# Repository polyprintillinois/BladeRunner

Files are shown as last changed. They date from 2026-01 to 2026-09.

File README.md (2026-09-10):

# BladeRunner - Linear Stage Controller

This repository accompanies **Hwang, Elangovan, Damron, Kwok, Jeon & Diao, "Democratizing Lab Automation through Multi-Agent-Assisted Design and 3D Printing"** (submitted, 2026). Archived release: [Zenodo DOI 10.5281/zenodo.22695750](https://doi.org/10.5281/zenodo.22695750). Code is released under the MIT licence; printed-part designs (STL) and documentation may be reused under the same terms with attribution.

**BladeRunner** is a high-precision linear stage control system powered by Arduino firmware and a Python Tkinter GUI. It provides safe, user-friendly control of a stepper-driven linear actuator with adjustable speed and acceleration.

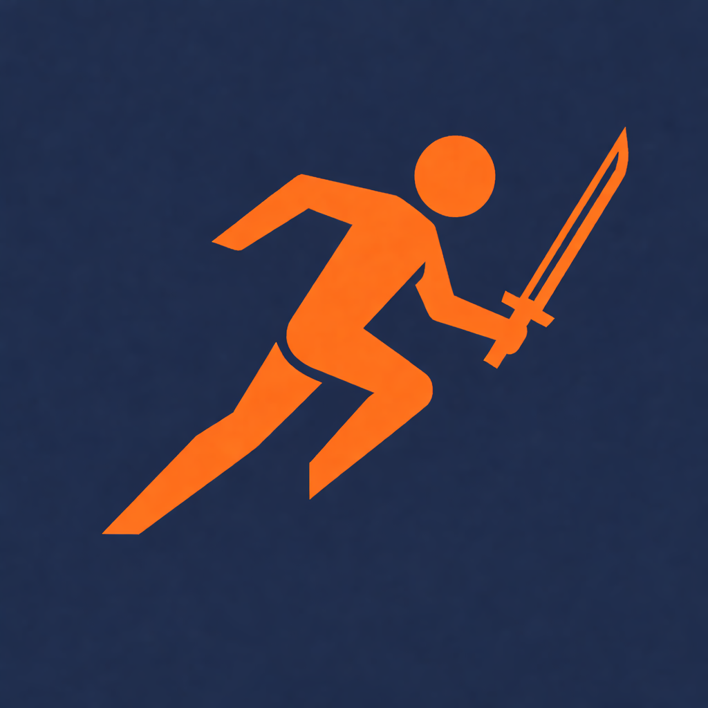
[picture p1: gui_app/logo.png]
BladeRunner Icon


## Documentation

- [Hardware Assembly Guide](docs/hardware-assembly-guide.md)
- [Implementation Guide](docs/implementation-guide.md)

To assemble, wire, and operate the system from scratch, use the Hardware Assembly Guide and Implementation Guide together.

## Features

- **Precise Control**: Move to absolute positions or jog in relative steps.
- **Reliable Operation**: Blocking homing routine, software stop (decelerated via `AccelStepper.stop()`), and software travel limits from 0 to 45 mm.
- **Adjustable Parameters**: Real-time control of speed (mm/s) and acceleration (mm/s^2).
- **Robust Communication**: Custom serial protocol with error handling and status feedback.

## Hardware Requirements

- **Microcontroller**: Arduino Uno R4 Minima
- **Driver**: Adafruit TMC2209 breakout in DIR/STEP mode
- **Motor**: NEMA 17 stepper motor (for example, StepperOnline 17HS08-1004S)
- **Actuator**: Linear rail/stage with 45 mm travel

## Safety

- The stage is driven by a 12 V supply. Disconnect power before wiring or swapping stepper leads.
- The carriage moves at up to 30 mm/s and can pinch fingers against the end stops; keep hands clear during homing and moves. The **EMERGENCY STOP** button performs a decelerated software stop via `AccelStepper.stop()`—it is not a hardware emergency stop.
- The blade is a thin glass or silicon piece with a sharp edge; handle it with tweezers.
- When printing with solvents (for example, chlorobenzene), operate inside a fume hood or with adequate ventilation. The 3D-printed PLA parts are not solvent-resistant and should be kept dry.

## Operating Constraints

- **Travel Limit**: The controller enforces a 45 mm software travel limit. Ensure the physical stage matches this usable range.
- **Homing Requirement**: The system must be homed after connecting before motion commands are enabled.
- **Blocking Homing**: The homing sequence blocks on the Arduino side until the limit switch is hit or the 20-second timeout expires. The software-stop command is still checked during this routine.
- **Speed and Acceleration Limits**: The GUI caps speed at 30 mm/s and acceleration at 1000 mm/s^2 to reduce the chance of stalls or mechanical damage.

## Installation and Usage

### Method 1: Executable

No Python installation is required.

1. Go to the **[Releases](../../releases)** page of this repository.
2. Download the latest `BladeRunner.exe` from the Assets section.
3. Connect the Arduino over USB and run the executable.

### Method 2: Run from Source

1. Install Python 3.x.
2. Install dependencies:

```bash
pip install -r requirements.txt
```

3. Run the application:

```bash
python gui_app/main.py
```

### Firmware Setup

1. Open `firmware/stepper_controller/stepper_controller.ino` in Arduino IDE.
2. Install the `AccelStepper` library.
3. Upload the firmware to the Arduino board.

## First Run (Hello World)

A minimal test that confirms the stage, firmware, and GUI are working takes about five minutes.

1. Flash `firmware/stepper_controller/stepper_controller.ino` to the Arduino Uno R4 Minima and connect it over USB. Connect the 12 V supply to the TMC2209 driver **last**.
2. Launch the GUI (`BladeRunner.exe` from the [Releases](../../releases) page, or `python gui_app/main.py`), select the Arduino's COM port, and click `Connect`. The button should change to `Disconnect`, and the status should read `CONNECTED` or `READY` after board startup.
3. Click `HOME AXIS (Required)` and confirm the prompt. The carriage should travel toward the limit switch, back off by approximately 2 mm, report `HOMED`, and reset the displayed position to `0.000 mm`.
4. Enter `20` in `Go To (mm)` and click `GO`; then enter `0` and click `GO` again. Confirm that the position display returns to `0.000 mm`. The specified unidirectional repeatability is ±6.3 µm.
5. Optional wet test: mount a glass slide, load approximately 10 µL of water under the blade, set the speed to `1 mm/s`, click `Set`, and run one 20 mm move. A continuous wetted track indicates the expected blade-substrate gap (approximately 100 µm with the printed holder).

If step 3 or 4 fails, disconnect the 12 V supply before checking the stepper wiring (see the [Hardware Assembly Guide](docs/hardware-assembly-guide.md)). If the carriage moves away from the switch during homing, reversing one coil pair reverses the motor direction; if the motor only vibrates, verify the coil-pair identification.

## Usage Guide

1. **Connect**: Select a COM port and click `Connect`.
2. **Home**: Click `HOME AXIS (Required)` to establish the zero position.
3. **Move**: Enter a target position in millimeters and click `GO`, or use the jog buttons.
4. **Set Parameters**: Adjust speed and acceleration as needed.
5. **Software Stop**: Press `EMERGENCY STOP` to request a decelerated software stop via `AccelStepper.stop()`.

## Project Structure

```text
BladeRunner/
|-- .zenodo.json                # Zenodo archive metadata
|-- LICENSE                     # MIT license
|-- dist/                        # Compiled executable output
|   `-- BladeRunner.exe
|-- firmware/
|   `-- stepper_controller/
|       `-- stepper_controller.ino
|-- docs/
|   |-- README.md
|   |-- hardware-assembly-guide.md
|   `-- implementation-guide.md
|-- gui_app/
|   |-- main.py                  # Tkinter application
|   |-- serial_link.py           # Serial communication layer
|   |-- app.ico                  # Executable icon
|   |-- icon.png                 # Window icon
|   `-- logo.png                 # App logo
|-- parts/                       # 3D-printed mechanical parts
|-- BladeRunner.spec             # PyInstaller spec file
`-- README.md
```

## License

BladeRunner is released under the [MIT License](LICENSE).

---
**BladeRunner Controller v1.0.2**<br>
Created by Changhyun Hwang (2026)

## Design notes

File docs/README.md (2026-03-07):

# BladeRunner Docs

This folder contains build and implementation documentation for the BladeRunner linear stage controller.

## Documents

- [Hardware Assembly Guide](hardware-assembly-guide.md): Mechanical parts, purchased components, wiring, and assembly workflow.
- [Implementation Guide](implementation-guide.md): Firmware, GUI, serial protocol, and system behavior.

## Current Scope

These documents reflect the current repository state:

- Arduino Uno R4 Minima controller
- Adafruit TMC2209 breakout in DIR/STEP mode
- StepperOnline 17HS08-1004S motor
- 45 mm software travel limit
- USB-powered Arduino and external 12 V motor supply

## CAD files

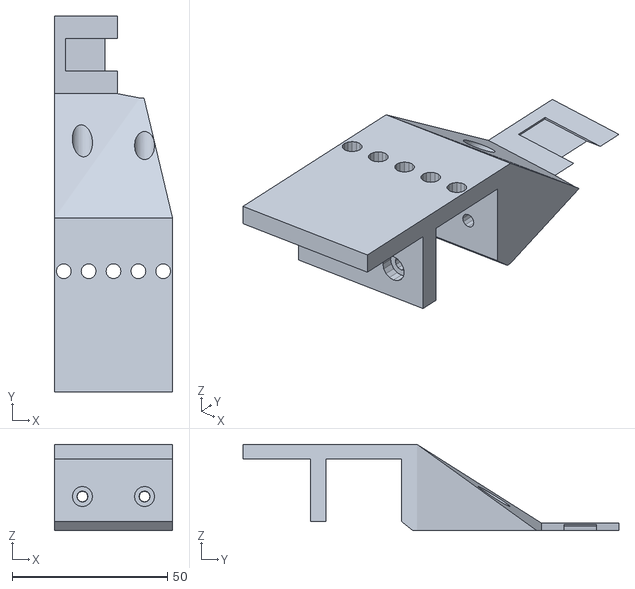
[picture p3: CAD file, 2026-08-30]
parts/bladeholder_connector.stl
38.0 x 121.0 x 27.8

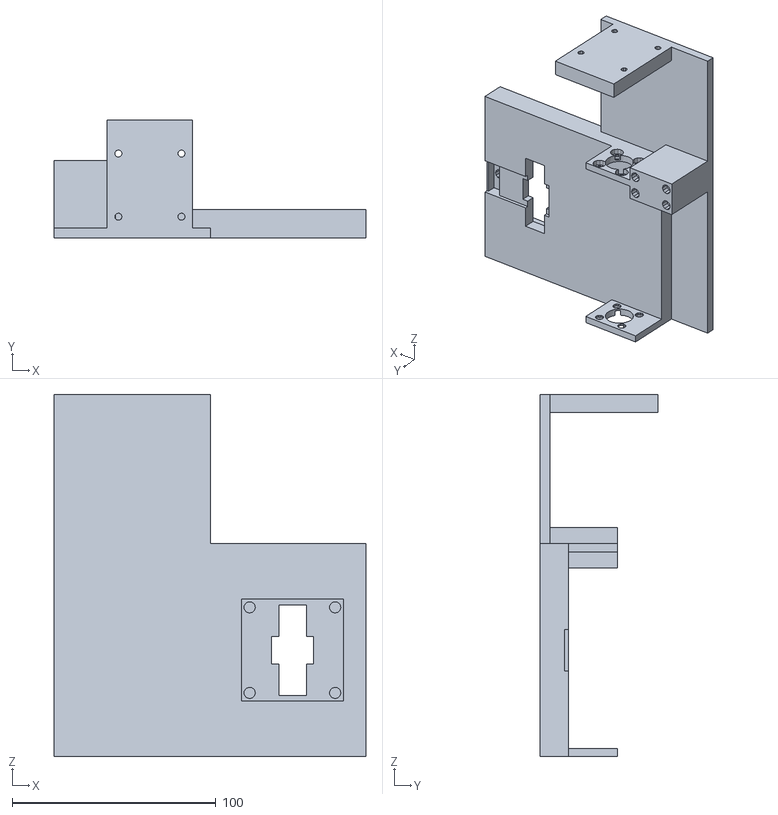
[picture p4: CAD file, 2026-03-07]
parts/baseplate.stl
153.0 x 58.0 x 177.8

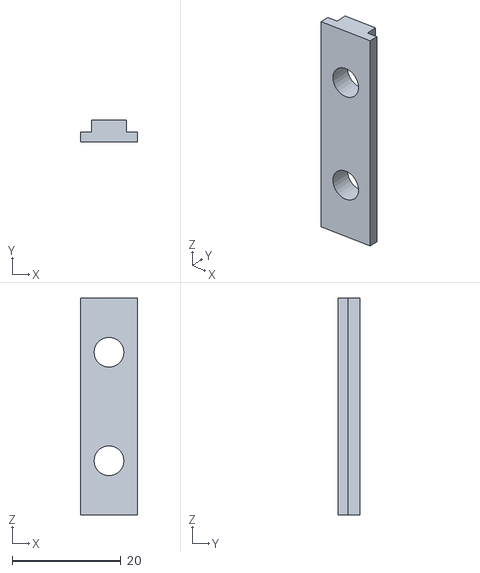
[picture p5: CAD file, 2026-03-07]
parts/fixer_double.stl
10.5 x 4.00 x 40.0

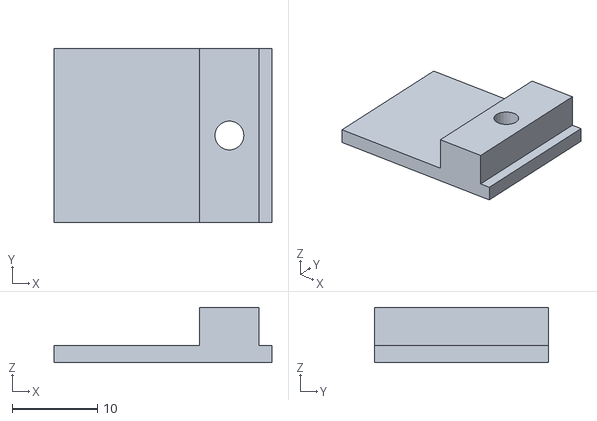
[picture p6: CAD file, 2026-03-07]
parts/substrate_fixer.stl
25.6 x 20.4 x 6.50

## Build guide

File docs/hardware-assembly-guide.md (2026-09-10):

# Hardware Assembly Guide

## Overview

BladeRunner is a compact linear stage built around a goBILDA open goRAIL, a lead screw drive, several 3D-printed interface parts, and an Arduino-controlled stepper system.

This guide covers:

- Purchased hardware
- 3D-printed parts
- Mechanical assembly order
- Electrical wiring
- Final setup checks

## System Summary

- **Controller**: Arduino Uno R4 Minima
- **Motor Driver**: Adafruit TMC2209 breakout
- **Stepper Motor**: StepperOnline 17HS08-1004S
- **Stage Format**: goBILDA open goRAIL with lead screw
- **Travel Range**: 45 mm usable software limit
- **Arduino Power**: USB
- **Motor Power**: External 12 V supply

## 3D-Printed Parts

Print all files in [parts](../parts/) before assembly.

| File | Purpose |
| --- | --- |
| `baseplate.stl` | Main mounting base for the motor and rail assembly |
| `bladeholder_connector.stl` | Connector between the lead screw nut and the blade holder |
| `fixer_double.stl` | Side clamping part used with the rail/bladeholder area |
| `substrate_fixer.stl` | Holds the substrate in place during experiments |

## Purchased Parts

### Control Electronics

| Item | Qty | Supplier | Part Number | Notes |
| --- | --- | --- | --- | --- |
| Arduino Uno R4 Minima | 1 | Arduino | Uno R4 Minima | Main controller |
| Adafruit TMC2209 | 1 | Adafruit | 6121 | Stepper driver, used in DIR/STEP mode |
| Arduino Perma-Proto board | 1 | Arduino | N/A | Used for power and wiring distribution |
| Stepper motor | 1 | StepperOnline | 17HS08-1004S | NEMA 17 motor |
| Snap-action switch | 1 | Digi-Key / Omron | V-153-1A5 | Used as the home/zero switch |

### Mechanical Actuator Parts

| Item | Qty | Supplier | Supplier PN | Notes |
| --- | --- | --- | --- | --- |
| Shaft coupler 8x5 mm | 1 | goBILDA | 4002-0005-0008 | Couples motor shaft to lead screw |
| Lead screw nut | 1 | goBILDA | 3503-0804-0038 | Mounts to bladeholder connector |
| Lead screw 150 mm | 1 | goBILDA | 3501-0804-0150 | Main drive screw |
| Open goRAIL 96 mm | 1 | goBILDA | 1118-0024-0096 | Main rail body |
| Lead screw clamping collar | 1 | goBILDA | 3504-0804-2109 | Screw retention/clamping component |
| Thrust ball bearing | 2 | goBILDA | 1613-0516-0008 | Axial load support |
| Flanged ball bearing | 1 pack | goBILDA | 1611-0514-0008 | Radial support for lead screw |

### Power Parts

| Item | Qty | Supplier | Part Number | Notes |
| --- | --- | --- | --- | --- |
| 12 V power adapter | 1 | Digi-Key / GlobTek | TR9CE5000LCP-N(R6B) | 12 V, 60 W motor supply |
| AC power cord | 1 | Digi-Key / Eaton Tripp Lite | P006-002-13A | Adapter input cable |
| Barrel jack connector set | 1 | Amazon / Thsinde | 5.5 mm x 2.5 mm pair set | Used on the perfboard power interface |

## Fasteners and Inserts

Most of the assembly uses:

- M3 heat-set inserts
- M3 screws
- M4 screws

Current usage mapping:

- **M4 screws**: goRAIL to baseplate, lead screw nut to bladeholder connector
- **M3 screws**: `fixer_double`, snap-action switch, and most remaining printed-part mounting points

## Mechanical Assembly

### 1. Print and prepare parts

1. Print all STL files in [parts](../parts/).
2. Install M3 heat-set inserts where required by the printed parts.
3. Confirm that the motor, rail, and printed interfaces fit without interference.

### 2. Build the base assembly

1. Mount the stepper motor to the `baseplate`.
2. Mount the open goRAIL to the `baseplate` using M4 hardware.

### 3. Assemble the internal goRAIL stack

Insert the following components into the goRAIL in this order:

1. Lead screw clamping collar
2. Thrust ball bearing
3. Flanged ball bearing
4. Lead screw nut
5. Flanged ball bearing
6. Thrust ball bearing
7. Flexible shaft coupler
8. Stepper motor

After alignment, connect the lead screw to the motor through the shaft coupler.

### 4. Attach the bladeholder interface

1. Attach `bladeholder_connector` to the lead screw nut using M4 screws.
2. Insert `fixer_double` into the goRAIL side area.
3. Secure the `fixer_double` assembly with M3 hardware.
4. Attach the blade holder or blade-specific interface to `bladeholder_connector`.

The blade itself is treated as experiment-specific hardware and should be selected separately.

### 5. Mount the home switch

1. Mount the Omron snap-action switch in the intended zeroing position.
2. Confirm that the moving assembly reliably actuates the switch at the home end of travel.
3. Adjust position as needed so the home trigger is repeatable.

### 6. Final experiment setup

1. Place the substrate into the fixture area.
2. Use `substrate_fixer` to clamp the substrate in place.
3. Verify that the blade path clears all fixtures before powering the motor.

## Electrical Wiring

The current firmware uses only `STEP`, `DIR`, and a single home switch input.

### Arduino Connections

| Arduino Pin | Connects To | Notes |
| --- | --- | --- |
| `D2` | TMC2209 `STEP` | Step pulse output |
| `D3` | TMC2209 `DIR` | Direction output |
| `D9` | Home switch signal | Configured as `INPUT_PULLUP` in firmware |
| `5V` | TMC2209 logic supply | Driver logic power |
| `GND` | TMC2209 logic ground and switch ground | Common reference |
| USB | PC | Arduino power and serial communication |

### TMC2209 and Motor Power

| Connection | Notes |
| --- | --- |
| External `12 V +` | To TMC2209 motor power input |
| External `12 V -` | To TMC2209 motor power ground |
| Motor coil A/B outputs | To the four motor wires on the stepper |

### Home Switch Wiring

Use the switch so that the firmware reads the input as:

- `HIGH`: not triggered
- `LOW`: triggered

That matches the current Arduino `INPUT_PULLUP` configuration. In practice, wire the switch between `D9` and `GND` using the switch terminals that close the circuit when the switch is actuated.

### Perfboard Power Distribution

The Perma-Proto board is used as a simple power distribution point:

1. Bring the 12 V adapter output onto the board through the barrel jack connector.
2. Route 12 V and GND from the perfboard to the TMC2209 motor power input.
3. Keep Arduino USB power separate from the motor power rail except for shared signal ground where required.

## Recommended Bring-Up Procedure

1. Power the Arduino over USB only and confirm serial connection.
2. Verify the home switch input before connecting motor power.
3. Apply 12 V motor power.
4. Confirm motor direction with a short jog.
5. Run homing and verify that the switch is hit cleanly.
6. Test motion over a short distance before using the full travel range.

## Checks Before Use

- Printed parts fit without rubbing or binding
- goRAIL is firmly mounted to the baseplate
- Lead screw rotates freely by hand before powered testing
- Bearings and collar are seated correctly
- Home switch triggers repeatably
- Arduino USB connection is stable
- 12 V motor power polarity is correct
- Stage motion is clear across the intended working range

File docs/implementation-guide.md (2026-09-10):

# Implementation Guide

## Overview

BladeRunner is split into two main software components:

- Arduino firmware in [firmware/stepper_controller/stepper_controller.ino](../firmware/stepper_controller/stepper_controller.ino)
- Python Tkinter GUI in [gui_app/main.py](../gui_app/main.py)

Serial communication is implemented in [gui_app/serial_link.py](../gui_app/serial_link.py).

## Repository Layout

| Path | Role |
| --- | --- |
| `firmware/stepper_controller/stepper_controller.ino` | Motion control firmware |
| `gui_app/main.py` | Desktop control UI |
| `gui_app/serial_link.py` | Serial transport and parser |
| `parts/` | 3D-printable hardware parts |
| `docs/` | Project documentation |

## System Architecture

### Control path

1. The user interacts with the Tkinter GUI.
2. The GUI sends simple ASCII commands over serial.
3. The Arduino firmware parses the command and updates the `AccelStepper` state.
4. The Arduino reports position and status back over serial.
5. The GUI updates labels, state flags, and logs from incoming messages.

### Motion model

- Motion is expressed in millimeters at the GUI level.
- Firmware converts millimeters to step counts using `stepsPerMm = 203.17`.
- The firmware enforces a motion range from `0.0` to `45.0` mm.
- The GUI requires a successful homing cycle before movement commands are allowed.

## Firmware Design

### Key Constants

The firmware currently defines:

- `stepsPerMm = 203.17`
- `minLimit = 0.0`
- `maxLimit = 45.0`
- `stepPin = 2`
- `dirPin = 3`
- `limitPin = 9`
- `HOMING_TIMEOUT_MS = 20000`
- `HOMING_SPEED_MM_S = 5.0`
- `HOMING_BACKOFF_MM = 2.0`

### Motion Calibration

`stepsPerMm = 203.17` was calibrated against commanded `6.000 mm` moves and independently verified optically (`202.6 ± 1.0 steps/mm`).

### Startup Behavior

At startup, the firmware:

1. Starts serial at `115200`
2. Configures the limit switch pin as `INPUT_PULLUP`
3. Applies default motion parameters
4. Reports `STATUS:READY`

### Motion Defaults

The firmware stores operator motion settings in:

- `userMaxSpeed`
- `userAcceleration`

Current defaults are:

- max speed: `5 mm/s`
- acceleration: `500 mm/s^2`

These settings are later restored after homing completes.

### Command Parsing

Each line from serial is parsed as:

- first character: command code
- remaining text: numeric value when needed

### Command Table

| Command | Example | Meaning |
| --- | --- | --- |
| `G` | `G12.5` | Move to an absolute position in mm |
| `J` | `J-1.0` | Jog by a relative distance in mm |
| `V` | `V5` | Set max speed in mm/s |
| `A` | `A500` | Set acceleration in mm/s^2 |
| `H` | `H` | Start homing |
| `S` | `S` | Request a software stop (decelerated via `AccelStepper.stop()`) |

### Homing Behavior

The homing routine is **blocking** on the Arduino side.

Flow:

1. Firmware reports `STATUS:HOMING_START`
2. Stage moves in the negative direction at the homing speed
3. The loop continues until:
   - the switch is triggered, or
   - the 20-second timeout is reached, or
   - a software-stop command is received
4. On successful switch hit, the position is zeroed
5. The stage backs off by `2.0 mm`
6. The position is zeroed again
7. Normal speed/acceleration settings are restored
8. Firmware reports `STATUS:HOMED`

Timeout result:

- `ERROR:HOMING_TIMEOUT`

Software-stop-during-homing result (the protocol string retains its original name):

- `STATUS:EMERGENCY_STOP_DURING_HOMING`

## Serial Output Format

### Position reports

The firmware sends a position report every 100 ms:

```text
P12.345
```

### Status messages

Status is reported as:

```text
STATUS:READY
STATUS:HOMING_START
STATUS:HOMING_BACKOFF
STATUS:HOMED
STATUS:STOPPED
```

Other messages may include warnings or errors such as:

```text
WARNING:Target_Out_Of_Bounds
ERROR:HOMING_TIMEOUT
```

## GUI Design

### Main Responsibilities

The GUI:

- Lists available COM ports
- Connects and disconnects from the Arduino
- Sends motion and parameter commands
- Displays live position and status
- Prevents motion until homing is complete
- Provides an operator-visible software-stop control labeled `EMERGENCY STOP`

### Connection Behavior

When the GUI connects:

1. The serial port opens at `115200`
2. DTR is toggled to reset the Arduino
3. The app waits for boot completion
4. The GUI sends its default motion parameters

That means GUI-side settings override firmware defaults after connection.

### GUI Limits

The GUI currently enforces:

- travel range: `0` to `45 mm`
- max speed input: `30 mm/s`
- max acceleration input: `1000 mm/s^2`

### State Handling

The GUI tracks:

- `is_connected`
- `is_homed`
- `current_position`
- `status_message`

Movement commands are blocked unless:

- the serial connection is active, and
- the stage has been homed

## Wiring Reference from Firmware

The current firmware implies this minimum electrical interface:

| Signal | Arduino Pin | Function |
| --- | --- | --- |
| `STEP` | `D2` | Step pulse output to driver |
| `DIR` | `D3` | Direction output to driver |
| `HOME_SW` | `D9` | Home switch input |

The home switch uses the Arduino internal pull-up, so the switch should pull the input low when actuated.

## Safety Model

Current safety behavior includes:

- software travel limit in firmware
- GUI-side move validation
- mandatory homing before motion
- software stop, decelerated via `AccelStepper.stop()`
- homing timeout

Current limitations:

- Firmware does not independently clamp incoming speed or acceleration to the same limits as the GUI
- Homing is blocking and occupies the Arduino loop until completion, timeout, or a software-stop command
- The system assumes the configured `stepsPerMm` matches the physical drive train

## Build and Run

### Firmware

1. Open `firmware/stepper_controller/stepper_controller.ino` in Arduino IDE.
2. Install the `AccelStepper` library.
3. Select the Arduino Uno R4 Minima board.
4. Upload the sketch.

### GUI from Source

1. Install Python dependencies:

```bash
pip install -r requirements.txt
```

2. Run:

```bash
python gui_app/main.py
```

### Packaged App

The repository also includes a PyInstaller spec:

- `BladeRunner.spec`

Use it when generating a Windows executable build.

## Recommended Future Improvements

- Add firmware-side clamps for speed and acceleration
- Add explicit driver configuration notes for the Adafruit TMC2209 breakout
- Document motor coil wiring with the exact wire color mapping used in the build

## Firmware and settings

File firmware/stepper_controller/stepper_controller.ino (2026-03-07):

#include <AccelStepper.h>

// --- Configuration & Calibration Data ---
const float stepsPerMm = 203.17; 
const float minLimit = 0.0;
const float maxLimit = 45.0;
const int stepPin = 2;
const int dirPin = 3;
const int limitPin = 9;

// Homing configuration
const unsigned long HOMING_TIMEOUT_MS = 20000; // 20 seconds
const float HOMING_SPEED_MM_S = 5.0;
const float HOMING_BACKOFF_MM = 2.0;

// User settings (Persisted)
float userMaxSpeed = 5.0 * stepsPerMm;
float userAcceleration = 500.0 * stepsPerMm; // Modified to 500 based on user preference

AccelStepper stepper(AccelStepper::DRIVER, stepPin, dirPin);

void setup() {
  Serial.begin(115200);
  pinMode(limitPin, INPUT_PULLUP);

  // Initial default settings
  stepper.setMaxSpeed(userMaxSpeed);
  stepper.setAcceleration(userAcceleration);
  
  Serial.println("STATUS:READY");
}

void loop() {
  if (Serial.available() > 0) {
    String input = Serial.readStringUntil('\n');
    processCommand(input);
  }

  stepper.run();

  // Real-time Position Report (100ms interval)
  static unsigned long lastReport = 0;
  if (millis() - lastReport > 100) {
    reportPosition();
    lastReport = millis();
  }
}

void processCommand(String input) {
  if (input.length() == 0) return;
  
  char cmd = input[0];
  float val = input.substring(1).toFloat();

  switch (cmd) {
    case 'G': // Absolute Move (Go to)
      if (val >= minLimit && val <= maxLimit) {
        stepper.moveTo(val * stepsPerMm);
      } else {
        Serial.println("WARNING:Target_Out_Of_Bounds");
      }
      break;
      
    case 'J': // Relative Move (Jog)
      {
        float target = (stepper.currentPosition() / stepsPerMm) + val;
        // Check soft limits
        if (target >= minLimit && target <= maxLimit) {
          stepper.moveTo(target * stepsPerMm);
        } else {
          Serial.println("WARNING:Target_Out_Of_Bounds");
        }
      }
      break;
      
    case 'V': // Set Max Speed
      userMaxSpeed = val * stepsPerMm;
      stepper.setMaxSpeed(userMaxSpeed); 
      break;
      
    case 'A': // Set Acceleration
      userAcceleration = val * stepsPerMm;
      stepper.setAcceleration(userAcceleration); 
      break;
      
    case 'H': // Homing
      runHoming(); 
      break;
      
    case 'S': // Emergency Stop
      stepper.stop(); 
      Serial.println("STATUS:STOPPED");
      break;
  }
}

void runHoming() {
  Serial.println("STATUS:HOMING_START");
  
  // Set homing speed
  stepper.setMaxSpeed(HOMING_SPEED_MM_S * stepsPerMm);
  stepper.setSpeed(-HOMING_SPEED_MM_S * stepsPerMm); // Move negative towards switch

  unsigned long startTime = millis();

  // Move until switch is hit, or timeout, or Cancelled
  while (digitalRead(limitPin) == HIGH) {
    // 1. Check Timeout
    if (millis() - startTime > HOMING_TIMEOUT_MS) {
      stepper.stop();
      Serial.println("ERROR:HOMING_TIMEOUT");
      // Restore settings even on error to be safe? 
      // safer to leave stopped, but let's restore to allow recovery
      stepper.setMaxSpeed(userMaxSpeed); 
      return;
    }

    // 2. Check Input for Emergency Stop
    if (Serial.available() > 0) {
      char emergencyCmd = Serial.peek(); // Peek first to see if it makes sense to read
      if (emergencyCmd == 'S') {
        Serial.read(); // Consume 'S'
        stepper.stop();
        Serial.println("STATUS:EMERGENCY_STOP_DURING_HOMING");
        // Restore settings
        stepper.setMaxSpeed(userMaxSpeed);
        return; 
      }
    }
    
    stepper.runSpeed();
  }

  // Current state: Switch hit or exited loop
  stepper.stop();
  stepper.setCurrentPosition(0);
  
  // Backoff
  Serial.println("STATUS:HOMING_BACKOFF");
  stepper.moveTo(HOMING_BACKOFF_MM * stepsPerMm);
  stepper.runToPosition();
  
  // Reset Zero
  stepper.setCurrentPosition(0);
  
  // Restore operational speed
  stepper.setMaxSpeed(userMaxSpeed);
  stepper.setAcceleration(userAcceleration); // Just in case, though only speed was changed
  Serial.println("STATUS:HOMED");
}

void reportPosition() {
  Serial.print("P");
  Serial.println(stepper.currentPosition() / stepsPerMm, 3);
}

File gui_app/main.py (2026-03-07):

import tkinter as tk
from tkinter import ttk, messagebox
from serial_link import SerialLink
import time
import os
import sys
import ctypes
from PIL import Image, ImageTk

# --- Constants ---
WINDOW_TITLE = "BladeRunner"
WINDOW_SIZE = "500x600" # Increased height
MAX_TRAVEL = 45.0
MIN_TRAVEL = 0.0
MAX_SPEED_LIMIT = 30.0
MAX_ACCEL_LIMIT = 1000.0 # Safety cap

def resource_path(relative_path):
    """ Get absolute path to resource, works for dev and for PyInstaller """
    try:
        # PyInstaller creates a temp folder and stores path in _MEIPASS
        base_path = sys._MEIPASS
    except Exception:
        base_path = os.path.dirname(__file__)

    return os.path.join(base_path, relative_path)

class LinearStageApp:
    def __init__(self, root):
        self.root = root
        self.root.title(WINDOW_TITLE)
        self.root.geometry(WINDOW_SIZE)
        
    # Set Icon
    # Set Icons
        try:
            base_path = os.path.dirname(__file__)
            images = []

            # 1. Taskbar Icon (Large) -> logo.png
            logo_path = resource_path("logo.png")
            if os.path.exists(logo_path):
                img_logo = Image.open(logo_path)
                images.append(ImageTk.PhotoImage(img_logo)) # High res for taskbar

            # 2. Title Bar Icon (Small) -> icon.png
            icon_path = resource_path("icon.png")
            if os.path.exists(icon_path):
                # Resize specifically for title bar preference
                img_icon = Image.open(icon_path).resize((16, 16), Image.LANCZOS)
                images.append(ImageTk.PhotoImage(img_icon))

            if images:
                self._icon_refs = images # Keep reference
                # Tkinter will choose the best size from the provided list
                self.root.iconphoto(False, *images)
                
        except Exception as e:
            print(f"Icon Error: {e}")

        self.serial = SerialLink(logger=self.log_message) # Pass logger
        self.is_homed = False # Safety flag
        
        # State variables for display
        self.current_speed_setting = 5.0
        self.current_accel_setting = 500.0
        
        self._init_ui()
        self._start_update_loop()

    # ... (rest of methods)

# ...



    def _init_ui(self):
        # 1. Connection Frame
        conn_frame = ttk.LabelFrame(self.root, text="Connection", padding=10)
        conn_frame.pack(fill="x", padx=10, pady=5)
        
        ttk.Label(conn_frame, text="Port:").pack(side="left")
        self.port_combo = ttk.Combobox(conn_frame, values=self.serial.get_ports(), width=10)
        self.port_combo.pack(side="left", padx=5)
        self.port_combo.bind("<Button-1>", self._refresh_ports)
        
        ttk.Button(conn_frame, text="Refresh", command=self._refresh_ports).pack(side="left", padx=2)
        
        self.btn_connect = ttk.Button(conn_frame, text="Connect", command=self._toggle_connection)
        self.btn_connect.pack(side="left", padx=5)

        # 2. Status & Position Display
        status_frame = ttk.Frame(self.root, padding=10)
        status_frame.pack(fill="x", padx=10)
        
        # Big Position Number
        self.lbl_pos = ttk.Label(status_frame, text="0.000 mm", font=("Helvetica", 24, "bold"))
        self.lbl_pos.pack()
        
        # Current Settings Display
        self.lbl_settings = ttk.Label(status_frame, text="Speed: -- | Accel: --", font=("Helvetica", 10))
        self.lbl_settings.pack(pady=(0, 5))
        
        self.lbl_status = ttk.Label(status_frame, text="DISCONNECTED", foreground="red")
        self.lbl_status.pack()

        # 3. Emergency Stop (Always Visible)
        stop_frame = ttk.Frame(self.root, padding=5)
        stop_frame.pack(fill="x", padx=10)
        self.btn_estop = tk.Button(stop_frame, text="EMERGENCY STOP", bg="red", fg="white", 
                                   font=("Arial", 12, "bold"), height=2, command=self._emergency_stop)
        self.btn_estop.pack(fill="x")

        # 4. Motion Control Frame (Compacted)
        self.control_frame = ttk.LabelFrame(self.root, text="Motion Control", padding=10)
        self.control_frame.pack(fill="x", padx=10, pady=5) # Removed expand=True
        
        # Homing
        ttk.Button(self.control_frame, text="HOME AXIS (Required)", command=self._cmd_home).pack(fill="x", pady=5)
        
        # Move Absolute
        abs_frame = ttk.Frame(self.control_frame)
        abs_frame.pack(fill="x", pady=5)
        ttk.Label(abs_frame, text="Go To (mm):").pack(side="left")
        self.ent_abs = ttk.Entry(abs_frame, width=10)
        self.ent_abs.pack(side="left", padx=5)
        ttk.Button(abs_frame, text="GO", command=self._cmd_move_abs).pack(side="left")

        # Jog
        jog_frame = ttk.Frame(self.control_frame)
        jog_frame.pack(fill="x", pady=5)
        ttk.Label(jog_frame, text="Jog Step (mm):").pack(side="left")
        self.ent_jog = ttk.Entry(jog_frame, width=10)
        self.ent_jog.insert(0, "1.0")
        self.ent_jog.pack(side="left", padx=5)
        
        self.btn_jog_neg = ttk.Button(jog_frame, text="<< [-]", command=lambda: self._cmd_jog(-1))
        self.btn_jog_neg.pack(side="left")
        self.btn_jog_pos = ttk.Button(jog_frame, text="[+] >>", command=lambda: self._cmd_jog(1))
        self.btn_jog_pos.pack(side="left")
        
        # 5. Motion Parameters (Moved up)
        set_frame = ttk.LabelFrame(self.root, text="Motion Parameters", padding=10)
        set_frame.pack(fill="x", padx=10, pady=5)
        
        # Speed
        ttk.Label(set_frame, text="Speed (mm/s):").pack(side="left")
        self.ent_speed = ttk.Entry(set_frame, width=5)
        self.ent_speed.insert(0, "5")
        self.ent_speed.pack(side="left", padx=5)
        
        # Accel
        ttk.Label(set_frame, text="Accel (mm/s²):").pack(side="left")
        self.ent_accel = ttk.Entry(set_frame, width=5)
        self.ent_accel.insert(0, "500")
        self.ent_accel.pack(side="left", padx=5)
        
        ttk.Button(set_frame, text="Set", command=self._cmd_set_params).pack(side="left")

        # 7. Credits (Packed bottom to ensure visibility)
        ttk.Label(self.root, text="Created by Changhyun Hwang (2026)", font=("Arial", 8), foreground="gray").pack(side="bottom", anchor="e", padx=10, pady=(5, 5))

        # 6. Terminal Log
        log_frame = ttk.LabelFrame(self.root, text="Terminal Log", padding=10)
        log_frame.pack(fill="both", expand=True, padx=10, pady=5)
        
        self.txt_log = tk.Text(log_frame, height=10, state="disabled", font=("Consolas", 9))
        self.txt_log.pack(fill="both", expand=True)



        # Initial State
        self._update_settings_display() # Default display
        


    def log_message(self, message):
        """Append message to log widget."""
        self.txt_log.config(state="normal")
        self.txt_log.insert("end", message + "\n")
        self.txt_log.see("end")
        self.txt_log.config(state="disabled")
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

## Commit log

2026-01-24 Complete Firmware and GUI: Safety Homing, Parameters, Refresh Button
2026-01-24 Docs: Correct motor brand to StepperOnline
2026-03-07 Add build docs and release updates
    # Conflicts:
    # README.md
    [baseplate.stl, bladeholder_connector.stl, fixer_double.stl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]
2026-08-30 Update bladeholder connector STL
    [bladeholder_connector.stl]
